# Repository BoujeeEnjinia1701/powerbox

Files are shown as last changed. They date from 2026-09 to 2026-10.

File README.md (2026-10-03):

# PowerBox

     

**Area:** CleanTech · **TRL:** 3 of 9 (proof of concept on paper) · **Value-engineering target:** USD 450, excluding the shared SwapCell pack (estimated cost USD 483) · **Difficulty:** 3 of 5

Standalone multi-input power station built around a SwapCell battery pack. It charges from a solar panel, the grid or a SunSpoke bike, and powers devices through USB, 12 V DC and a small AC outlet. It never connects to household wiring.

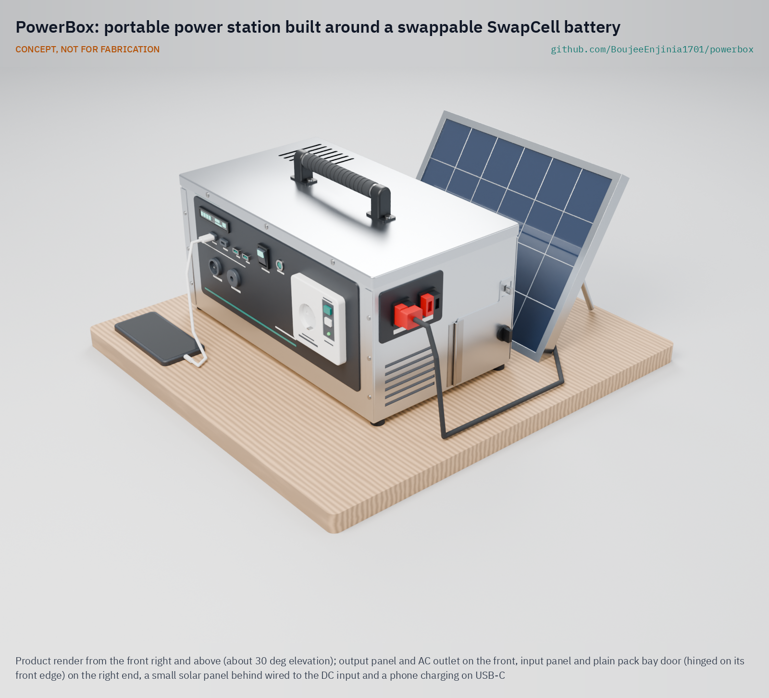
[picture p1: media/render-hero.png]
PowerBox: portable power station built around a swappable SwapCell battery, product render


[Exploded render](media/render-exploded.png) · [Detail render](media/render-detail.png) · [Interactive 3D model](media/viewer.html) · [Concept blueprint (PDF)](media/concept-blueprint.pdf) · [General arrangement (PDF)](cad/drawings/PBX-DWG-001.pdf) · [Prototype build plan](docs/05-build-plan.md) · [Design decisions](docs/06-design-decisions.md) · [Review note](docs/REVIEW.md)

## Concept rationale

A power station is only as useful as its battery, and in most commercial units the battery is sealed in. PowerBox is built around the portfolio's shared SwapCell pack instead, so the same battery can charge on a SunSpoke e-bike, a SwapCell dock or a solar panel and then run lights, phones, a radio and a router at home. A worn pack is replaced rather than the whole box. The box has no AC inlet and grid charging goes through a certified external charger, so it cannot back-feed household wiring through an ordinary plug.

The design is open and garage-buildable because the households that need it most are often the ones least served by sealed, imported products. A folded aluminium case, off-the-shelf certified modules for everything at mains voltage and a documented BOM mean a local technician can build, diagnose and repair it, and a community charging point can swap packs between boxes.

## Burning platform

In 2023 more than 666 million people still had no access to electricity, 85 % of them in sub-Saharan Africa ([WHO, IEA, IRENA, UNSD, World Bank, *Tracking SDG 7*, 2025](https://www.who.int/news/item/25-06-2025-energy-access-has-improved--yet-international-financial-support-still-needed-to-boost-progress-and-address-disparities)). Many more are connected but cannot rely on the grid: South Africa had load shedding on 290 days and for 6,948 hours in 2023, its worst year on record ([CSIR, 2025](https://www.csir.co.za/sites/default/files/2025-09/Utility%20Statistics%20Report_Jan%202025_Final.pdf)).

Rich grids fail too, and long outages fall hardest on poorer households. After Hurricane Maria in 2017, Puerto Rico lost an estimated 3.9 billion customer hours of electricity, the longest blackout in US history, and low-income residents waited longest for power to return ([Román et al., *PLOS ONE*, 2019](https://journals.plos.org/plosone/article?id=10.1371%2Fjournal.pone.0218883)).

## Where it could be used

### By industry

| Industry | Use |
| --- | --- |
| Households | Evening light, phone charging, radio and home internet through outages, recharged from solar or the grid |
| Community charging and small retail | Phone and lamp charging for a fee at market stalls and kiosks, with packs swapped between boxes and a dock |
| Humanitarian and disaster response | Quiet, fume-free power in shelters and homes after storms, earthquakes and grid attacks |
| Last-mile e-mobility | A home end for SunSpoke and other SwapCell vehicles, so a ridden pack powers the house at night |
| Education and training | A teaching platform for batteries, MPPT, inverters and electrical safety in schools and makerspaces |
| Electronics repair trade | An open, standard-parts design that local technicians can build, service and adapt |

### By country or region

| Country or region | Why it matters there |
| --- | --- |
| Nigeria | About 40 % of people lacked electricity access in 2023, and connected households saw about seven outages a week ([World Bank, *Atlas of Global Development*](https://data360.worldbank.org/en/atlas/electricity-access/)) |
| Democratic Republic of the Congo | About 80 % of the population lacked electricity access in 2023 ([World Bank, *Atlas of Global Development*](https://data360.worldbank.org/en/atlas/electricity-access/)) |
| South Africa | Load shedding on 290 days in 2023 ([CSIR, 2025](https://www.csir.co.za/sites/default/files/2025-09/Utility%20Statistics%20Report_Jan%202025_Final.pdf)) |
| Ukraine | Attacks destroyed about 9 GW of generating capacity by 2024, and some cities had blackouts of 12 h or more a day that summer ([UN Human Rights Monitoring Mission in Ukraine, 2024](https://ukraine.ohchr.org/en/Attacks-On-Ukraines-Electricity-Infrastructure)) |
| Puerto Rico (United States) | Hurricane Maria caused the longest blackout in US history, with rural municipalities averaging 131 days without power ([Román et al., 2019](https://journals.plos.org/plosone/article?id=10.1371%2Fjournal.pone.0218883)) |
| Japan | The 2018 Hokkaido Eastern Iburi earthquake cut power to about 2,950,000 homes across almost all of Hokkaido ([Japanese Red Cross Society](https://www.jrc.or.jp/english/relief/2020/0804_009751.html)) |

## What sparked the idea

The starting point was Winter Storm Uri in February 2021, when much of Texas lost power for days in freezing weather. The Texas Department of State Health Services counted 246 storm-related deaths, including 19 fatal carbon monoxide poisonings from improper use of generators, grills and heating equipment ([Texas DSHS, 2021](https://www.dshs.texas.gov/sites/default/files/news/updates/SMOC_FebWinterStorm_MortalitySurvReport_12-30-21.pdf)). The fuel-burning fallbacks that households reach for in an outage can be deadly indoors. That points at a silent battery box with no combustion and no way to back-feed the house, sized realistically for lights, phones, radio and internet, and charged from whatever is at hand.

## Problem

When the power goes out, households need a small, safe store of electricity for lights, phones, radio and internet, charged from whatever source is available: a solar panel, the grid when it is up or a charged pack brought home from an e-bike. Design with, not for: requirements must come from co-design sessions and field trials with the intended users through a local partner.

## Concept

Standalone multi-input power station built around a SwapCell battery pack. It charges from a solar panel, the grid or a SunSpoke bike, and powers devices through USB, 12 V DC and a small AC outlet. It never connects to household wiring.

It builds to SwapCell interface v0.3 as a station host: it wakes the pack through a coded INTERLOCK loop and can run loads while charging from solar. The sizing note shows 419 Wh usable per pack, 1.87 evenings of the reference load (1.81 with minimum-capacity cells, against a 1.8-evening target), a 2.1 h grid charge, 9.4 kg with the pack for the constructable design, and USD 482 of PowerBox parts against a USD 450 value-engineering target.

Full design precis: [docs/02-concept.md](docs/02-concept.md) · Sizing: [docs/04-calcs/01-sizing.md](docs/04-calcs/01-sizing.md) · General arrangement: [cad/drawings/PBX-DWG-001.pdf](cad/drawings/PBX-DWG-001.pdf)

## Key components

- Removable SwapCell 48 V pack (interface v0.3), with a fixed 12.8 V LiFePO4 pack as a documented fallback
- Multi-input charge controller (12 to 60 V DC and solar input with MPPT, external certified charger)
- USB-A and USB-C PD outlets
- 12 V DC outlets from a 30 A buck converter
- 300 W, 230 V pure sine inverter with its own AC outlet behind a 30 mA RCD
- State-of-charge display
- Enclosure with ventilation and handles

The working bill of materials is in [bom/bom.csv](bom/bom.csv).

## Building the prototype

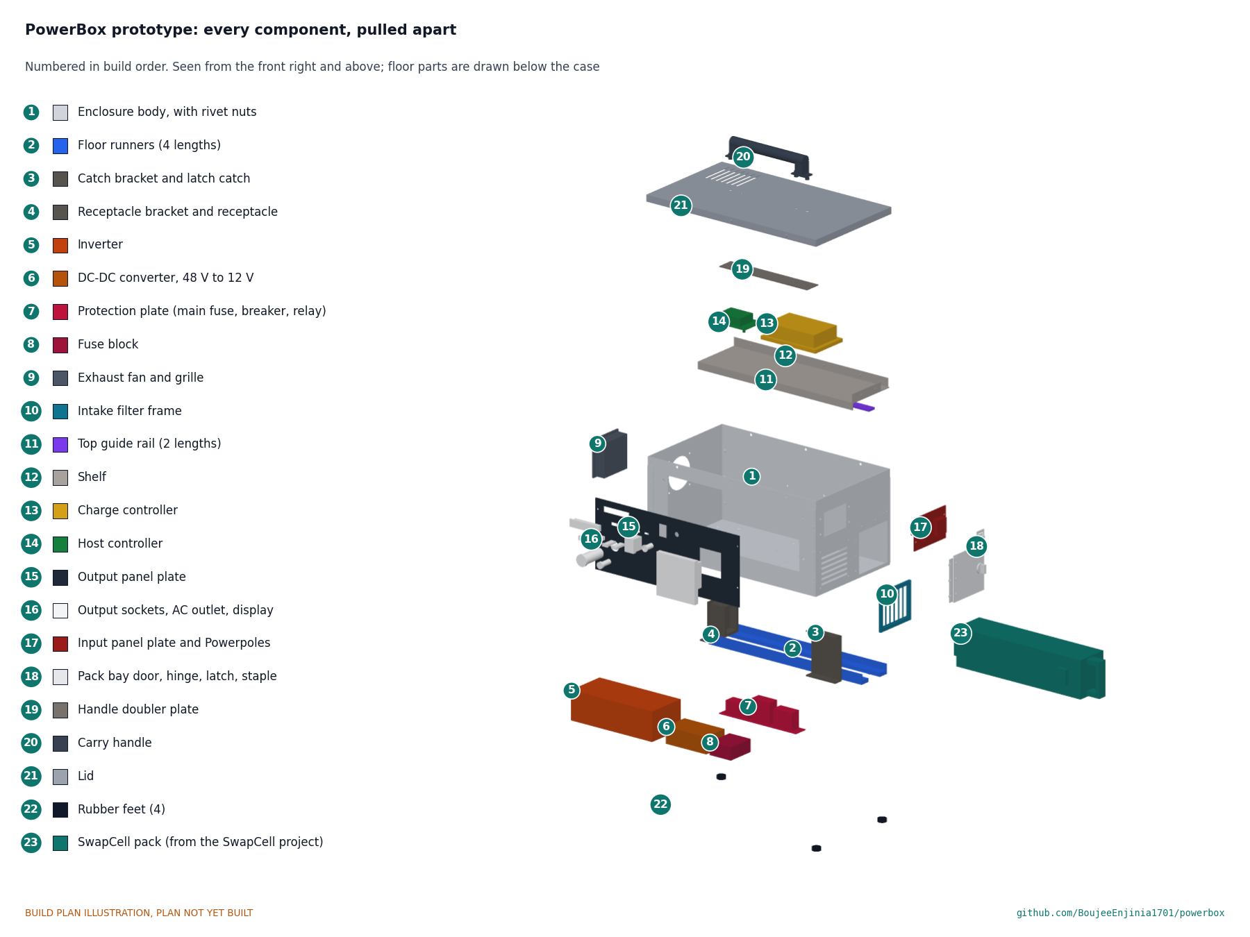
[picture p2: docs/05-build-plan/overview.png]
PowerBox prototype: every component pulled apart and numbered in build order


The [prototype build plan](docs/05-build-plan.md) (PBX-BLD-001) shows, in pictures, how to make each of PowerBox's 23 components and put them together in sixteen steps; nothing has been built yet. The made parts are a folded aluminium case, lid and shelf, two folded brackets, a door and two panel plates cut from sheet, and printed runners, a guide rail and a filter frame; the power modules are bought and wired at block level. Writing the plan made the design buildable: the lid now fits over the walls, the pack rests on guided runners, the shelf, brackets and receptacle are fixed, the door has a hinge, cam latch and padlock hasp, and the sockets sit in panel plates over windows in the walls (PBX-DDR-003, accepted by Amish on 2026-10-02). Every picture is drawn from the model, which checks that each part touches what it should and clears what it should not.

## Safety

> Standalone use only: never connect the AC output to a wall outlet or household wiring, because back-feeding endangers utility workers and is illegal. Contains a lithium battery pack. Use a BMS with cell-level protection, fuse the pack, and charge on a non-combustible surface.

## Repository layout

| Folder | Contents |
| --- | --- |
| `docs/` | Problem, concept, requirements, calculations and design decisions |
| `cad/src/` | build123d Python source, the source of truth for all geometry |
| `cad/step/`, `cad/stl/` | Exported models for FreeCAD, other CAD tools and printing |
| `cad/drawings/` | 2D sketches and dimensioned drawings |
| `bom/` | Bill of materials |
| `electronics/` | KiCad schematics and PCB layouts |
| `firmware/` | Microcontroller code |
| `media/` | Renders, perspectives and photos |
| `build-log/` | Dated prototyping notes |

## Documentation

Controlled documents follow the portfolio [documentation standard](.kit/STANDARDS.md). Each carries a document ID (PBX-PRC-001 for the precis), a version and a revision history. Branded PDFs are built with `python .kit/render.py` and attached to GitHub Releases when a document is tagged, for example `PBX-PRC-001/v1.0`.

## Credits

Designed by Amish Chadha. See [CONTRIBUTORS.md](CONTRIBUTORS.md) for roles. To cite this design, use [CITATION.cff](CITATION.cff) (GitHub shows it as "Cite this repository").

AI assistance (Claude) was used to accelerate concept renders, prototype documentation and first-pass sizing calculations. Design direction and all decisions are Amish Chadha's, recorded in this repository's decision records (`docs/decisions/`).

## Licenses

- **Hardware** (CAD, drawings, BOM, electronics): [CERN-OHL-S v2](LICENSE)
- **Software** (firmware, scripts, notebooks): [MIT](LICENSE-SOFTWARE)

A project of the [Design Molecule](https://designmolecule.com) lab.

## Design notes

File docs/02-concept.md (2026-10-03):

---
doc_id: PBX-PRC-001
title: PowerBox design precis
project: PowerBox
doc_type: Design precis
version: "0.8"
status: Draft
date: '2026-10-02'
author: Amish Chadha
license: CERN-OHL-S-2.0
revisions:
- version: "0.1"
  date: '2026-09-24'
  author: Amish Chadha
  change: Initial scaffold
- version: "0.2"
  date: '2026-09-24'
  author: Amish Chadha
  change: Populate to TRL 2 (architecture, first-order numbers, input and output specification, safety, media)
- version: "0.3"
  date: '2026-09-24'
  author: Amish Chadha
  change: Removed StepGen as a charging source after StepGen became a walking vehicle (Amish, 2026-09-24)
- version: "0.4"
  date: '2026-09-25'
  author: Amish Chadha
  change: TRL 3. SwapCell interface v0.3 (wake, station mode, latch class); Amish's decisions recorded (PBX-DDR-001); numbers checked against PBX-CAL-001; 30 A buck; general arrangement PBX-DWG-001
- version: "0.5"
  date: '2026-09-25'
  author: Amish Chadha
  change: Recommendations accepted by Amish (DDR-002)
- version: "0.6"
  date: '2026-10-01'
  author: Amish Chadha
  change: Constructable design (PBX-DDR-003), with lid, bay, door and panel details, mass, size and cost; budget treated as a value-engineering target
- version: "0.7"
  date: '2026-10-02'
  author: Amish Chadha
  change: "Decisions of 2026-10-02: R2 restated (met on paper), national AC socket with bonded earth, bare aluminium case, lit rocker switch, per-port metering, theft resistance, first candidate partner type, SwapCell transition action"
- version: "0.8"
  date: '2026-10-02'
  author: Amish Chadha
  change: "Cost USD 483 (USD 33 over the target) with the lit rocker main switch (PBX-CAL-001 v0.4); figures and pictures regenerated"
---

# PowerBox design precis

PowerBox is an aluminium carry case about the size of a small toolbox (460 x 260 x 220 mm body, 480 x 279 x 275 mm overall) with a SwapCell pack sliding into a bay through an end door. A charge controller takes DC from a solar panel, a certified external charger takes grid power, and a charged pack from a SunSpoke bike can simply be swapped in. Power leaves through USB-C PD, USB-A, 12 V sockets and one 300 W, 230 V pure sine AC outlet behind a 30 mA RCD. It never connects to household wiring. The sizing note PBX-CAL-001 shows one pack gives 419 Wh usable, which runs the reference evening of lights, phones, radio and a router **1.87 times (1.81 with minimum-capacity cells), above the 1.8 evenings of R2** as Amish restated it on 2026-10-02. The constructable design (PBX-DDR-003) weighs about 9.4 kg with the pack. Value-engineering target: USD 450. Estimated cost of the constructable design: USD 483 without the pack (USD 33 over the target). How to build the prototype is in the build plan PBX-BLD-001.

PowerBox builds to **SwapCell interface v0.3**. It is a station host (item C), so it can run loads while charging from solar; its receptacle carries the 10 kΩ INTERLOCK coding resistor that wakes a sleeping pack (item W); and its bay uses a class D latch catch (item V).

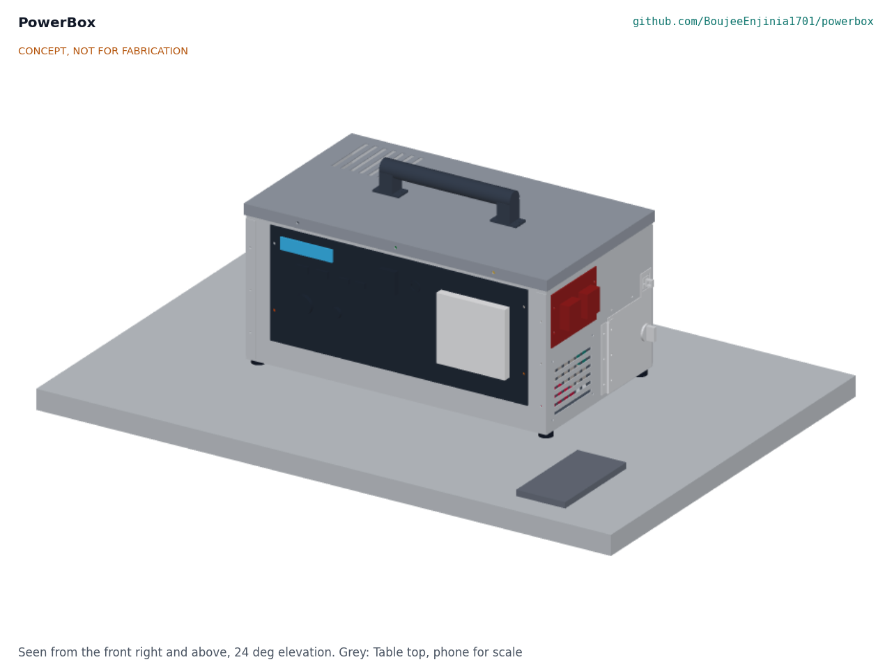
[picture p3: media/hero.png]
Hero render


*Figure 1. PowerBox on a table, with a phone for scale. Output panel on the front, input panel and pack bay door on the right end. Rendered from the parametric model `cad/src/model.py`.*

## How it works

1. **Charge.** Energy comes in through one of three paths, all controlled by the host controller:
   - **DC input** (a solar panel or another 12 to 60 V DC source, up to 200 W) goes through a buck-boost charge controller that tracks the source's maximum power point and charges the pack at up to 54.6 V.
   - **Grid** goes through a certified external 54.6 V, 5 A charger brick with a DC plug. PowerBox itself has no AC inlet, so it cannot be plugged into anything that would back-feed.
   - **SunSpoke** charges the pack while riding or at its own 100 W panel. The rider brings the charged SwapCell pack home and swaps it in. SunSpoke's panel can also plug into the DC input directly. StepGen, a walking vehicle, runs on the same SwapCell pack, so a pack can move between PowerBox and StepGen in the same way.
2. **Store.** The SwapCell pack (13S2P lithium-ion, 46.8 V nominal, 468 Wh nameplate) lies on one of its guide faces on floor runners, with its latch face toward the front of the case, and mates through the SwapCell blind-mate connector at the far end of the bay. A class D catch on a bracket at the front of the bay takes the pack's latch pawl, and the closed door stops the handle.
3. **Wake and handshake.** Seating the pack closes the INTERLOCK loop through the receptacle's 10 kΩ coding resistor, which wakes the pack. With no heartbeat after 2 s the pack enters legacy discharge (15 A limit), which powers the host; the host then sends a station heartbeat (host type 3) requesting mode 2 (discharge) or mode 4 (charge-discharge). A pack that fell asleep in the bay is woken with a recessed wake button on the front panel, which briefly opens the INTERLOCK loop.
4. **Convert and deliver.** The 39 to 54.6 V bus feeds a 48 V to 12 V, 30 A buck converter for the 12 V sockets and the USB-C PD and USB-A modules, and a 48 V input, 300 W pure sine inverter for the AC outlet. The inverter is switched in through its own relay and pre-charge resistor.
5. **Charge while in use.** When a source and a load are both present the host requests mode 4 and keeps net charge current at or below 5.0 A. With the grid charger connected (a fixed 5 A), the host limits the solar controller to the present load current.
6. **Inform.** A small display shows state of charge, input and output power and estimated time remaining, read from the pack's CAN messages, and the energy and charge sessions counted per port, labelled as approximate and not for billing. The host switches the inverter off after 10 min below 5 W and returns to off after 30 min idle.
7. **Protect.** A 30 A main fuse, a 20 A breaker on the inverter feed, per-output fuses, thermostatic fan control and the pack's own BMS limits guard against faults.

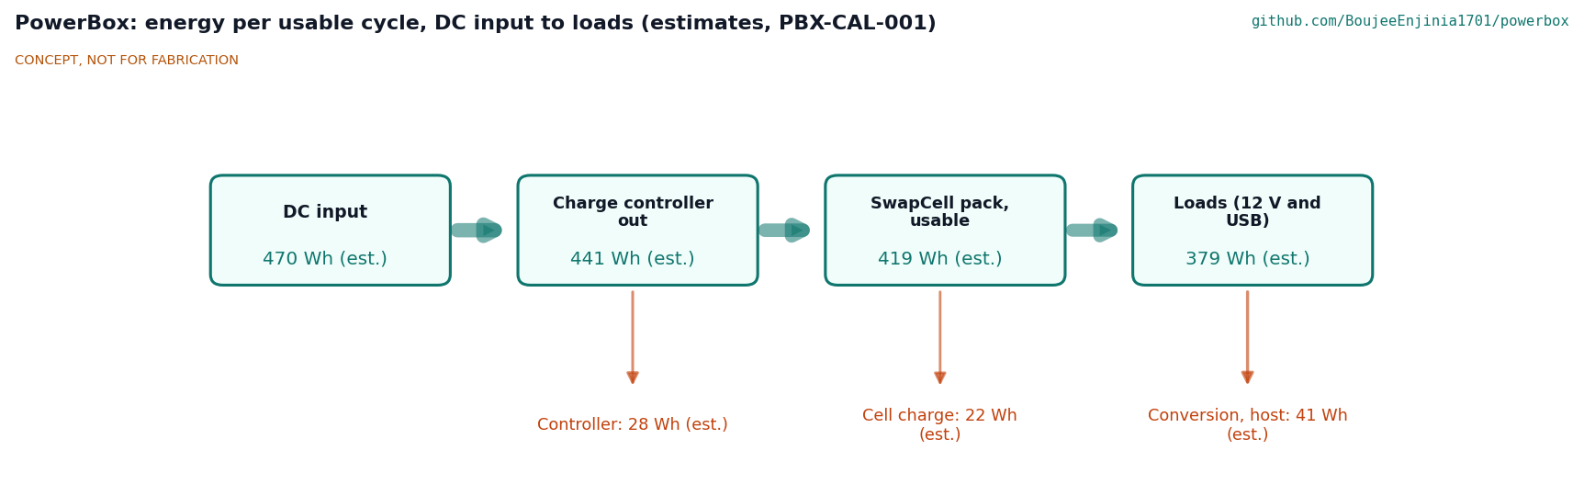
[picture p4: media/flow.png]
Energy flow


*Figure 2. Energy per usable cycle, DC input to loads, from PBX-CAL-001. All values are estimates: controller 94 %, cell charge 95 %, output conversion for the reference evening mix of 12 V and USB loads.*

## Main components

*Table 1. Main components. Numbers match `bom/bom.csv` and Figure 4.*

| # | Component | Choice | Notes |
| --- | --- | --- | --- |
| 1 | Enclosure body | Folded 1.2 mm aluminium tub, 460 x 260 x 220 mm | Spreads heat and resists fire better than plastic. Decided by Amish, 2026-09-25 |
| 2 | Lid | 1.2 mm aluminium with a 12 mm skirt and exhaust slots at the back | Removable for service |
| 3 | Carry handle | Folding bar handle on the lid, 200 mm span | Rated 15 kg or more |
| 4 | SwapCell pack | SwapCell interface v0.3 reference pack, 468 Wh, 2.85 kg | Priced once in the SwapCell BOM, not here. Removable pack decided by Amish, 2026-09-25 |
| 5 | Pack bay | Printed floor runners with guide lips and a top guide rail (1 mm clearance per side), folded catch bracket with the class D catch, folded 2 mm shelf above, SwapCell receptacle on a floating mount with a 10 kΩ INTERLOCK coding resistor | Horizontal side-loading bay decided by Amish, 2026-09-25 |
| 6 | Pack bay door | Door on the right end, hinged on its front edge, thumb-turn cam latch, padlock hasp and staple (PBX-DDR-003) | Second stop behind the pack handle |
| 7 | Multi-input charge controller | Buck-boost DC-DC, 12 to 60 V in, 200 W, CC-CV output set by the host | One DC input decided by Amish, 2026-09-25; MPPT in host firmware |
| 8 | Host controller | ESP32 with CAN transceiver, relays and current sensors | SwapCell station host; charge control, auto-off, display |
| 9 | Inverter | 300 W pure sine, 48 V input, 600 W for 1 s, 230 V 50 Hz, output isolated so the neutral can be bonded | AC region decided by Amish, 2026-09-25 |
| 10 | DC-DC converter | 48 V to 12 V, 30 A buck | Resized from 20 A by PBX-CAL-001 |
| 11 | Output panel | USB-C PD 100 W and 60 W, 2 x USB-A, 2 x 12 V sockets, lit rocker main switch, recessed wake button | Front face |
| 12 | AC outlet | Single 230 V outlet behind a 30 mA RCD | Only mains-voltage point on the box |
| 13 | Display | 2.4 in TFT or e-paper | State of charge, power in and out, time left |
| 14 | Input panel | 2 x Anderson Powerpole PP45: DC in, charger in | Right end, above the bay door |
| 15 | Exhaust fan | 80 mm 12 V fan, thermostatic; filtered intake slots on the right end | Pulls air across the case and out of the left end and lid |

Items 16 (protection and wiring), 17 (grid charger brick) and 18 (hardware) are in the BOM but not modelled. The general arrangement is drawing PBX-DWG-001 (`cad/drawings/PBX-DWG-001.pdf`), generated from `cad/src/model.py`.

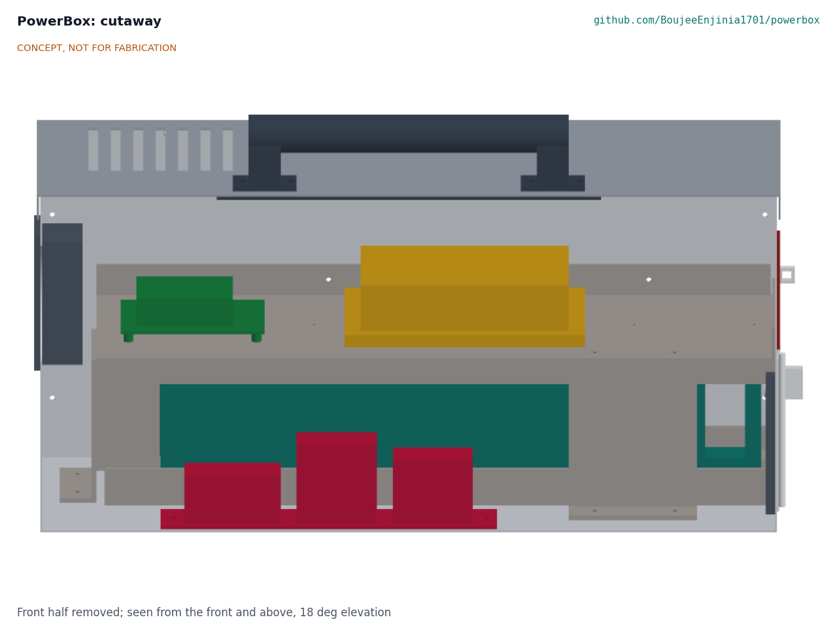
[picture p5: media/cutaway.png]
Cutaway


*Figure 3. Section looking from the front: inverter (9) on the floor at the front, SwapCell pack (4) in its bay at the back, charge controller (7) and host (8) on the shelf above, fan (15) on the left end, input panel (14) and bay door (6) on the right end.*

## Key numbers

All values come from PBX-CAL-001 (`docs/04-calcs/sizing.py`) and are paper estimates. Assumptions: the SwapCell v0.3 reference pack (466 Wh at 0.2C, 39.0 to 54.6 V); 10 to 100 % state of charge; 12 V buck 94 %, USB modules 93 % from 12 V, charge controller 94 % nominal, cell charge 95 %, grid charger 90 %; inverter efficiency and idle draw typical of 48 V, 300 W pure sine units (no datasheet yet).

*Table 2. Energy, charge times, size and cost.*

| Quantity | Value | Basis | Requirement |
| --- | --- | --- | --- |
| Usable energy | 419 Wh (407 Wh with minimum cells) | 90 % of 466 Wh | R1 met (400 Wh) |
| Reference evening (Table 1 of PBX-REQ-001) | 225 Wh from the pack | 165 Wh for 12 V loads at 94 %, 55 Wh for USB at 87 %, 5 Wh host and idle converters over 5 h | |
| Evenings per pack | 1.87 | 419 / 225 | R2 met on paper (target 1.8, restated 2026-10-02) |
| Grid charge, 10 to 100 % | 2.1 h; 492 Wh from the wall | 1.5 h CC at 5 A, then 0.6 h CV; charger 90 % | R4 met (3 h) |
| Solar, 200 W panel | 634 Wh per clear day at the pack; full in 0.70 day | 4.5 peak sun hours, 0.75 derating, 94 % controller | R5 met |
| Solar, SunSpoke 100 W panel | 317 Wh per clear day; one evening in 0.75 day | Same basis | |
| Charge controller efficiency | 90.5 % at 12 V and 200 W; 93 % or more elsewhere from 40 to 200 W | Loss model, no datasheet | R6 at risk |
| Station mode, net charge | 4.48 A worst case; 2.74 A typical with the router | 200 W at 94 % into 42 V; limit 5.0 A | Within the SwapCell limit |
| 12 V bus demand, all DC outputs | 318 W, 26.5 A | 120 W sockets plus 184 W USB at 93 % | 30 A buck (was 20 A) |
| Peak pack current | 11.5 A at 400 W output; 20.9 A during a 1 s inverter surge | At 39.0 V | Within 20 A continuous and 35 A peak |
| Inverter idle, if left on | 192 Wh per day, 46 % of usable | 8 W for 24 h | Auto-off after 10 min (R8) |
| Standby, off | 3.2 % per month | 2.5 % self-discharge plus 100 µA BMS sleep | R8 met (5 %) |
| Standby, ready | 0.6 W, 14.4 Wh per day | ESP32 0.2 W, CAN and BMS 0.2 W, display 0.2 W | R8 met (1.0 W); host returns to off after 30 min idle |
| Heat at full load while charging | 60 W; air rise about 6 K with the fan | Inverter 41 W, buck 6.4 W, controller 12 W, host 1 W | Fan needed |
| Mass | 9.4 kg (20.8 lb) with pack | Pack 2.85, body 1.22, lid 0.47, inverter 1.20, other parts 3.68 kg (constructable design) | R10 met (10 kg); charger brick about 0.8 kg extra |
| Size | 480 x 279 x 275 mm overall | Parametric model | R10 met, 5 mm spare in height |
| PowerBox parts cost | USD 483 | `bom/bom.csv`, indicative prices | Value-engineering target USD 450: USD 33 over |
| Cost with one SwapCell pack | USD 897, for reference | USD 483 plus USD 414 from the SwapCell BOM | Pack excluded from this budget (decided) |

*Table 3. Runtime on one full pack (419 Wh usable) for single loads.*

| Load | Output | Power at the load | Drawn from the pack | Runtime |
| --- | --- | --- | --- | --- |
| Wi-Fi router and fibre terminal | 12 V DC | 12 W | 12.8 W | about 33 h |
| Three 5 W LED bulbs | 12 V DC | 15 W | 16.0 W | about 26 h |
| Radio | 12 V DC | 5 W | 5.3 W | about 79 h |
| Phone charges | USB | 12 Wh each | 13.7 Wh each | about 31 charges |
| Laptop | USB-C PD | 45 W | 51.5 W | about 8 h |
| Small LED TV | AC | 60 W | 70.6 W | about 6 h |
| Desk fan | AC | 25 W | 32.1 W | about 13 h |
| Maximum AC load | AC | 300 W | 340.9 W | about 1.2 h |
| Refrigerator or kettle | AC | Out of scope: starting surge or power beyond the 300 W inverter | | |

*Table 4. Input and output specification.*

| Port | Type and connector | Voltage | Power or current | Notes |
| --- | --- | --- | --- | --- |
| DC in | Anderson PP45, red and black | 12 to 60 V DC | 200 W maximum, 16.7 A at 12 V | Solar panel or SunSpoke panel; MPPT; TVS and reverse-polarity protection; 20 A fuse |
| Charger in | Anderson PP45, keyed differently from DC in | 54.6 V DC from the certified brick | 5 A | Grid charging only through the external charger |
| Pack | SwapCell blind-mate connector, interface v0.3 | 39.0 to 54.6 V | 20 A continuous available; PowerBox uses 11.5 A or less | CAN 2.0B at 250 kbit/s; 120 Ω termination in PowerBox; 10 kΩ INTERLOCK coding resistor; station host type 3 |
| USB-C PD 1 | USB-C | 5 to 20 V | 100 W | Laptops |
| USB-C PD 2 | USB-C | 5 to 20 V | 60 W | Phones, tablets |
| USB-A 1, 2 | USB-A | 5 V | 12 W each | Phones, lamps, radios |
| 12 V DC 1 | Car socket | 12 V regulated | 10 A shared with 12 V DC 2 | Router, lights, radio |
| 12 V DC 2 | 5.5 x 2.1 mm barrel | 12 V regulated | As above | |
| AC out | One 230 V socket behind a 30 mA RCD: the national socket of the first partner's country with its earth pin bonded to the case, never a universal socket | 230 V 50 Hz, pure sine | 300 W continuous, 600 W for 1 s | Auto-off; never to be connected to household wiring |
| Total output | | | 400 W | Host limit to keep pack current and heat in range |

## Key design choices

All of these were decided by Amish on 2026-09-25 (go with recommendation), PBX-DDR-001, unless marked otherwise.

- **Removable SwapCell pack, with a fixed internal pack as fallback.** One battery moves between PowerBox, SunSpoke and the SwapCell dock, and a worn pack is replaced without discarding the box. The fixed 12.8 V LiFePO4 pack (about 30 Ah, 384 Wh, about $110) with a 12 V inverter and no CAN stays only as a documented fallback.
- **Side-loading horizontal bay.** Laying the pack along the case length with a door on the end keeps the case low and stable; a top-loading bay would make it about 450 mm tall.
- **One DC input with maximum power point tracking.** A second independent input (about $30 more) only if users need two panels at once.
- **Grid charging only through a certified external charger.** No mains-input electronics in the box and no AC inlet. The brick can be omitted where a SwapCell dock is on hand ($399 of parts).
- **A 300 W, 230 V AC outlet, with a DC-only variant.** The DC-only variant saves about $92 and removes all mains voltage from the box. 120 V 60 Hz is a later variant.
- **Folded aluminium enclosure.**
- **No human-powered input now.** A pedal generator could later be a separate repo that plugs into the DC input.
- **Station host on SwapCell interface v0.3.** Wake through the coded INTERLOCK loop (item W), charge-discharge mode 4 as a station host (item C) and a class D latch catch with the door as a second stop (item V). These replace the keep-alive cell and local pass-through workarounds considered at TRL 2.
- **Budget.** `budget_usd` stays at USD 450, a value-engineering target rather than a limit (Amish, 2026-10-01), and covers the PowerBox parts, including the grid charger; the SwapCell pack is priced once in the SwapCell BOM.
- **Wake button, 30 A buck and fuse ratings.** Proposed in PBX-CAL-001 and decided by Amish, 2026-09-25: go with recommendation (PBX-DDR-002). A recessed, normally closed wake button in series with the 10 kΩ coding resistor; a 30 A (360 W) 48 V to 12 V buck; every 48 V fuse rated 60 V DC or more with at least 1 kA breaking capacity, as in PBX-CAL-001 Table 3.

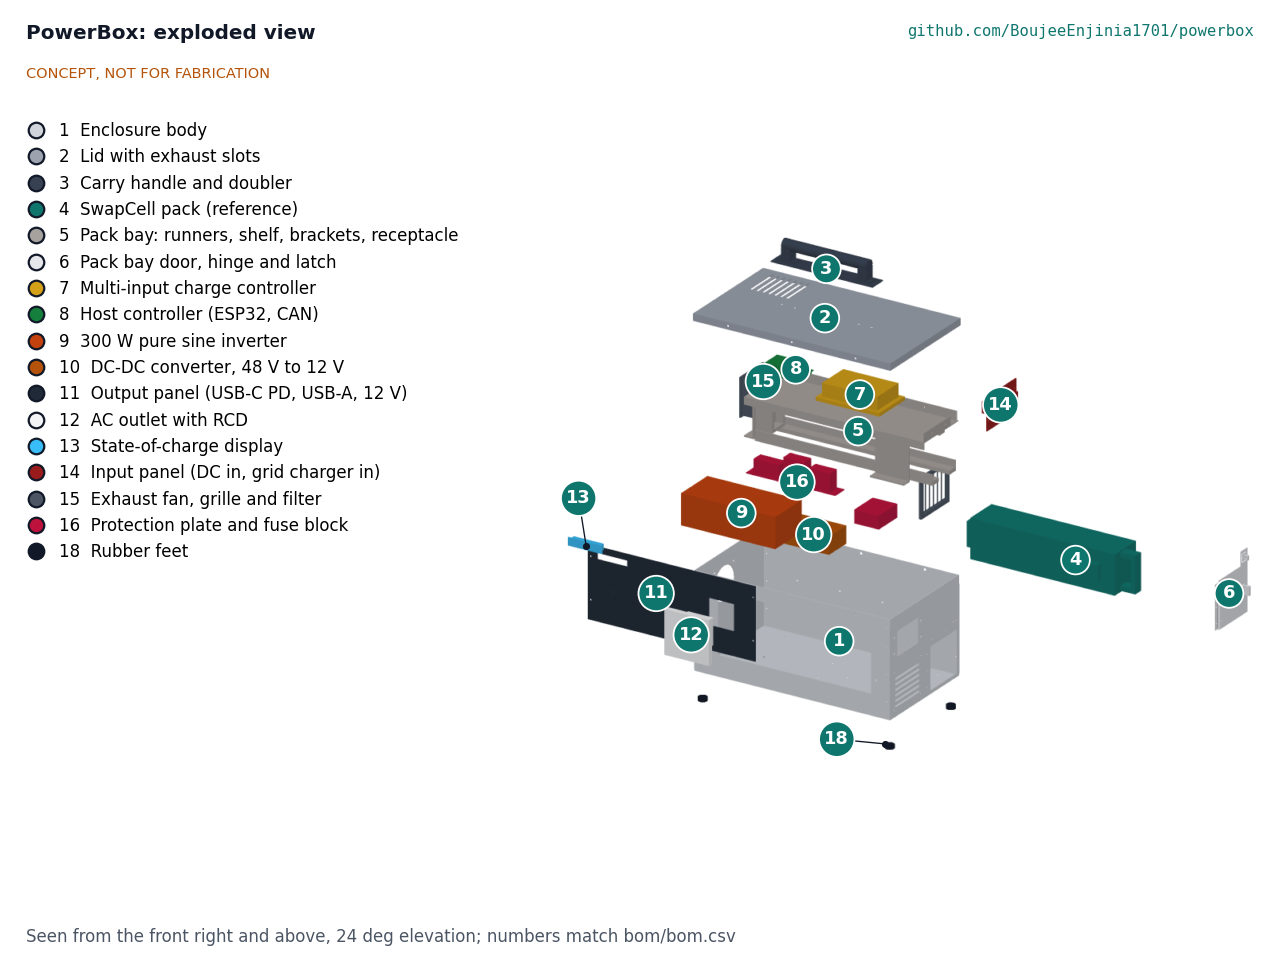
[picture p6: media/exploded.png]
Exploded view


*Figure 4. Exploded view with BOM numbers.*

## Safety

> **Safety:** PowerBox is standalone only. Never connect the AC outlet to a wall outlet, household wiring, a distribution board or a transfer switch. Back-feeding can kill utility workers repairing lines during an outage, can damage the box and the home's wiring, and is illegal.

> **Safety:** The SwapCell pack is a 468 Wh lithium-ion battery that can deliver about 500 A into a short. Use it only with the SwapCell BMS, keep the pack's fuse and PowerBox's 30 A main fuse in place, and never charge a damaged, swollen or wet pack. Charge on a non-combustible surface, away from exits, beds and children, and do not cover the box while charging. Keep a smoke alarm in the room.

> **Safety:** The AC outlet carries 230 V. It is behind a 30 mA RCD, and for the RCD to work the inverter's output neutral must be bonded to the case and the protective earth pin, as in a vehicle or boat installation. This needs an inverter whose output is isolated from its DC input; many small inverters float or are not isolated. This must be confirmed from the chosen inverter's datasheet before any build.

- **AC socket and case finish.** The AC outlet is the national socket of the first partner's country, with its earth pin bonded to the case; never a multi-standard universal socket, which can accept a plug without a reliable earth contact and defeat the RCD arrangement. The case is the earth bond for the RCD: it stays bare 5052 aluminium for the prototype, and any later powder coat must leave the bond points bare (decided by Amish, 2026-10-02).
- **No back-feed by design.** There is no AC inlet on the box, and grid charging uses a certified external charger with a DC plug, so no cable can join PowerBox's AC output to a live circuit through an ordinary plug. The user guide and labels must still warn against double-male cords and improvised connections.
- **Extra-low-voltage bus.** The battery side stays at 54.6 V or less, below the 60 V DC limit for extra-low voltage, so only the inverter output and the charger brick input are at mains voltage.
- **Fuse ratings.** Every fuse on the 48 V side must be rated for 60 V DC or more and at least 1 kA breaking capacity, because a short at the pack could draw about 496 A (PBX-CAL-001 section 6).
- **Coded interlock.** The receptacle must carry the 10 kΩ coding resistor. A direct link from INTERLOCK to SGND reads as a fault and the pack stays dead, which fails safe. The wake button opens the loop, so pressing it while the box is running cuts the output briefly; it is recessed to prevent accidental presses.
- **Charging while in use.** In mode 4 PowerBox acts as a charger. The host keeps net charge at or below 5.0 A and the pack voltage at or below 54.6 V, and limits the solar controller whenever the fixed 5 A grid charger is connected. The pack refuses charge below 0 °C and above 45 °C cell temperature.
- **Ventilation.** At full load while charging the case holds about 60 W of heat. A thermostatic fan pulls air through filtered intake slots on the right end and out through the left end and lid. The host derates or shuts outputs down above an internal temperature limit, and the pack enforces its own limits. The case must not be used in a closed cupboard or bag.
- **Cords and connectors.** Keyed Powerpole connectors prevent the charger and DC inputs from being swapped. Input and output cords must be rated for their current, kept out of walkways and never run under rugs. The 12 V sockets are fused at 10 A.
- **Pack handling.** The bay door keeps fingers away from the connector, and the SwapCell interlock keeps the pack output dead until it is fully seated.
- **Not a medical or life-safety supply.** PowerBox must not be relied on for oxygen concentrators or other life-support equipment.

## Open questions

Items that remain open after PBX-DDR-001 and PBX-DDR-002. None of them is TRL 4 work to be started now; TRL 4 is on hold by Amish's instruction.

- **R2 (decided 2026-10-02).** Restated as 1.8 evenings; the 10 % cut-off is kept and the reference evening is revisited with the first partner's users.
- **Legacy-to-station transition.** SwapCell interface v0.3 does not say whether a pack in legacy discharge accepts a station heartbeat and moves to mode 2 or 4 without opening its output. PowerBox's host is powered from the pack and depends on this. Kept with SwapCell as one cross-repo action shared with MotionCore, with an answer needed before PowerBox's interface is frozen; if the answer is no, a small hold-up capacitor for the host is planned across the mode change (decided by Amish, 2026-10-02).
- **Inverter selection.** Confirm idle draw, light-load efficiency and an isolated output whose neutral can be bonded for the RCD.
- **Charge controller selection (R6, at risk).** Confirm 90 % or more at 12 V and 200 W and at 40 W, and stable tracking.
- **Value engineering (R11).** The constructable design is USD 33 over the USD 450 value-engineering target on indicative prices; the savings worth trying are in the design decisions register (PBX-DEC-001).
- **Theft resistance and metering (decided 2026-10-02).** Thumb-turn cam latch and padlock hasp for the prototype, a keyed cam latch if the first partner runs an unattended or shared charging point; per-port energy and session counts on the display, not for billing.
- **First co-design partner (decided 2026-10-02).** A partner in a 230 V, 50 Hz region that runs or supplies community charging or solar home systems; the first candidate type to approach is a solar distribution charity such as SolarAid, which works in Zambia and Malawi. Nothing is agreed. The load profile, pack-swap routine and price must be validated with users.

Concept media: [blueprint sheet](../media/concept-blueprint.pdf), [interactive 3D model](../media/viewer.html).

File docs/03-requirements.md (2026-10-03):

---
doc_id: PBX-REQ-001
title: PowerBox requirements
project: PowerBox
doc_type: Requirements
version: "0.7"
status: Draft
date: '2026-10-02'
author: Amish Chadha
license: CERN-OHL-S-2.0
revisions:
- version: "0.1"
  date: '2026-09-24'
  author: Amish Chadha
  change: Initial scaffold
- version: "0.2"
  date: '2026-09-24'
  author: Amish Chadha
  change: First measurable requirements for TRL 2
- version: "0.3"
  date: '2026-09-24'
  author: Amish Chadha
  change: Removed StepGen as a charging source after StepGen became a walking vehicle (Amish, 2026-09-24)
- version: "0.4"
  date: '2026-09-25'
  author: Amish Chadha
  change: TRL 3. Record Amish's decisions (PBX-DDR-001), including the 230 V AC region and a budget that excludes the pack; SwapCell interface v0.3; status from PBX-CAL-001
- version: "0.5"
  date: '2026-10-01'
  author: Amish Chadha
  change: R10 and R11 status for the constructable design (PBX-DDR-003, PBX-CAL-001 v0.2); budget treated as a value-engineering target
- version: "0.6"
  date: '2026-10-02'
  author: Amish Chadha
  change: "R2 restated as 1.8 evenings (Amish, 2026-10-02, PBX-DEC-001 item 5); met on paper"
- version: "0.7"
  date: '2026-10-02'
  author: Amish Chadha
  change: "R11 cost restated to USD 483, USD 33 over the target, after the lit rocker main switch (PBX-CAL-001 v0.4)"
---

# PowerBox requirements

These requirements are checked by calculation in PBX-CAL-001 (TRL 3). They are still proposals, not user-validated needs, and will be revised after co-design sessions. On paper, nine are met, including R2 as restated by Amish on 2026-10-02 (1.87 evenings against 1.8); R6 is at risk, R11 is reported against its value-engineering target (USD 33 over), and R12 cannot be verified until users try a pack swap. The Status column gives the TRL 3 result.

| ID | Requirement | Target | Verification (TRL 3 or later) | Status (PBX-CAL-001) |
| --- | --- | --- | --- | --- |
| R1 | Store useful energy in one SwapCell pack | 400 Wh or more usable at the pack terminals, using 10 to 100 % state of charge | Calculation from SwapCell capacity and the host's discharge cut-off | Met, 419 Wh |
| R2 | Run a household through outage evenings | 1.8 evenings of the reference load profile (Table 1, 203 Wh at the loads) on one full pack, at the pack's 10 % cut-off (restated from 2 evenings by Amish on 2026-10-02, PBX-DEC-001 item 5) | Energy budget calculation including conversion losses and standby | Met on paper: 1.87 evenings (1.81 with minimum-capacity cells) |
| R3 | Accept four charging sources | (a) DC input 12 to 60 V, up to 200 W, with maximum power point tracking for a solar panel or another DC source; (b) grid through a certified external charger; (c) SunSpoke by swapping in a charged SwapCell pack; (d) SunSpoke's 100 W panel through the DC input | Design review against the input specification table | Met (design review) |
| R4 | Recharge quickly from the grid | 10 to 100 % in 3 h or less | Charger rating and SwapCell charge curve | Met, 2.1 h |
| R5 | Recharge from solar in a day | 10 to 100 % in one clear day (4.5 peak sun hours) with a 200 W panel | Solar yield calculation | Met, full in 0.70 day |
| R6 | Use DC and solar input efficiently at low power | DC input conversion efficiency 90 % or more from 40 to 200 W, and stable maximum power point tracking (no stall or hunting) as a panel's output changes with light and temperature | Converter efficiency data; later bench test with a solar panel or solar simulator | At risk, 90.5 % worst case in the loss model |
| R7 | Provide the outputs households use | 2 x USB-C PD (one 100 W, one 60 W), 2 x USB-A (12 W each), 2 x 12 V DC (10 A shared), 1 x AC outlet, 230 V 50 Hz, 300 W continuous pure sine (THD 3 % or less) behind a 30 mA RCD; total output limited to 400 W | Design review against the output specification table | Met (design review) |
| R8 | Waste little energy when idle | Off: 5 % or less of pack energy per month, including cell self-discharge. Ready (display on, outputs off): 1.0 W or less. Inverter switches itself off after 10 min below 5 W | Standby budget calculation; later measurement | Met, 3.2 % per month off, 0.6 W ready |
| R9 | Never back-feed household wiring | No AC input connector that can mate with an AC output; AC output only through a 30 mA RCD outlet with the inverter neutral bonded to the case; grid charging only through a certified external charger with a DC plug; DC bus 60 V or less | Design review and safety checklist | Met (design review) |
| R10 | Be carried by one adult | 10 kg (22 lb) or less with pack; 500 x 300 x 280 mm or smaller including handle; one top handle | Massing model, then weighing | Met, 9.4 kg, 480 x 279 x 275 mm (constructable design) |
| R11 | Keep to the value-engineering target | PowerBox parts against a value-engineering target of USD 450 (a hypothetical control target, not a limit; Amish, 2026-10-01), including the grid charger and excluding the SwapCell pack, which is priced once in the SwapCell BOM (decided by Amish, 2026-09-25) | Priced BOM | USD 483, USD 33 over the target |
| R12 | Swap packs and show status simply | Pack swapped by hand in 30 s or less without tools; display shows state of charge, input and output power and estimated time remaining, read from the SwapCell interface v0.3 CAN messages; a sleeping pack wakes through the INTERLOCK loop (v0.3 item W) | Design review; later timed trial with users | Not verifiable at TRL 3 |

## Assumptions

Table 1. Reference evening load profile (6 pm to 11 pm outage). Proposed for review; the real profile must come from co-design sessions.

| Load | Power | Hours | Energy at the load | Output used |
| --- | --- | --- | --- | --- |
| Three LED bulbs | 3 x 5 W | 5 | 75 Wh | 12 V DC |
| Wi-Fi router and fibre terminal | 12 W | 5 | 60 Wh | 12 V DC |
| Radio | 5 W | 4 | 20 Wh | 12 V DC |
| Four phone charges | about 12 Wh each | | 48 Wh | USB |
| **Total** | | | **203 Wh** | |

- The SwapCell pack is the reference 13S2P pack of SwapCell interface v0.3: 46.8 V nominal, 39.0 to 54.6 V, 468 Wh nameplate and 466 Wh at 0.2C (SWC-CAL-001). PowerBox is a station host (v0.3 item C) and its receptacle carries the 10 kΩ INTERLOCK coding resistor (item W).
- Solar input spends much of the day well below the panel rating (morning, evening and cloud), so the DC input often runs at 40 to 100 W.
- Refrigerators, kettles and other high-power or high-surge loads are out of scope (see PBX-PRB-001).
- Budget: the USD 450 value-engineering target in `project.yaml` covers the PowerBox itself (decided by Amish, 2026-09-25, PBX-DDR-001). A household that needs its own pack also buys a SwapCell pack, priced once in the SwapCell BOM at about $414 in prototype parts.
- R2: decided by Amish on 2026-10-02 (PBX-DEC-001, item 5): 1.8 evenings, which covers minimum-capacity cells (1.81); the 10 % cut-off is kept, since discharging to 3.5 % would shorten the shared SwapCell pack's life. The 203 Wh reference evening is not yet validated and is revisited with the first partner's users.

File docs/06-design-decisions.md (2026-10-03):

---
doc_id: PBX-DEC-001
title: PowerBox design decisions register
project: PowerBox
doc_type: Design decisions register
version: "0.3"
status: Draft
date: '2026-10-02'
author: Amish Chadha
license: CERN-OHL-S-2.0
revisions:
  - version: "0.1"
    date: '2026-10-01'
    author: Amish Chadha
    change: Register opened with the build plan; budget treated as a value-engineering target
  - version: "0.2"
    date: '2026-10-02'
    author: Amish Chadha
    change: "Amish approved the recommendations for all twelve open decisions on 2026-10-02 (PBX-DDR-003 accepted); moved to decisions made"
  - version: "0.3"
    date: '2026-10-02'
    author: Amish Chadha
    change: "Cost USD 483 (USD 33 over the target) with the lit rocker main switch; savings figure USD 433 without the grid charger"
---

# PowerBox design decisions register

Every design decision still to be made, and every decision made, in one place. Each decision is argued in full in its decision record under `docs/decisions/`; this register is the index Amish works from. The build plan (`docs/05-build-plan.md`) describes the design as it stands and does not list open decisions.

## Open decisions

None. All open decisions were decided on 2026-10-02.

## To confirm when parts are bought

| # | What to confirm | Why it matters | Source |
| --- | --- | --- | --- |
| 1 | The inverter's output is isolated from its DC input so its neutral can be bonded to the case and earth pin; its idle draw and light-load efficiency | The 30 mA RCD only works with a bonded neutral; idle draw sets the auto-off case | PBX-CAL-001 section 8; PBX-PRC-001 |
| 2 | The charge controller reaches 90 % or more at 12 V and 200 W and at 40 W, and tracks stably | R6 is at risk on the loss model | PBX-CAL-001 section 3 |
| 3 | The fuse block and its blade fuses are rated 58 V DC or more, and every 48 V fuse 60 V DC or more with at least 1 kA breaking capacity | A short at the pack could draw about 496 A | PBX-CAL-001 section 6; PBX-DDR-003 |
| 4 | The hole patterns of the class D catch, the receptacle's floating mount, and the inverter's and converter's feet | The catch bracket web, receptacle bracket web and floor holes are drilled to suit | PBX-DDR-003 |
| 5 | The cam latch grips a 1.2 mm door against a 1.2 mm wall, and its tongue reaches 15 mm | The tongue must turn behind the end wall | PBX-DDR-003, P7 |
| 6 | The cut-out sizes of every module in the output and input panel plates | The plate cut-outs are drawn from envelopes, not datasheets | PBX-DWG-110, PBX-DWG-111 |
| 7 | The rivet nut hole size (6.0 mm assumed for M4) and the heat-set insert hole sizes (5.6 mm for M4, 4.0 mm for M3) | Each maker gives its own | PBX-DDR-003 |
| 8 | The fan's flow through the filter, grille and 76 mm hole (half of 16 L/s free air assumed) | The 6 K air rise at full load depends on it | PBX-CAL-001 section 9 |

## Value engineering

Value-engineering target: USD 450 (a hypothetical control target, not a limit). Estimated cost of the constructable design: USD 483 for the PowerBox parts, excluding the shared SwapCell pack (USD 33 over the target). Main cost drivers and savings worth trying:

- The largest lines are the inverter (USD 70), the grid charger brick (USD 50), the output panel modules (USD 46), the protection parts and wiring (USD 38), the enclosure body (USD 38), the pack bay (USD 40), and the charge controller and buck converter (USD 30 each).
- Making the design constructable added USD 33 over the concept's USD 449: rivet nuts and windows in the body, the deeper lid skirt, the handle doubler, the shelf, brackets, runners and rail, the door hinge, cam latch and staple, the filter frame, the protection plate and the counted fixings.
- Savings worth trying: leave out the grid charger where a SwapCell dock is on hand (USD 50, bringing the parts to USD 433); the DC-only variant without the inverter and AC outlet (about USD 92, and no mains voltage in the box); quotes for the folded sheet parts as one batch from one shop; printing the brackets in place of folding them is not worth trying, since they carry the pack's latch load.

## Decisions made

| Date | Decision | Decided by | Record |
| --- | --- | --- | --- |
| 2026-09-24 | StepGen removed as a charging source; the DC input stays for solar and other DC sources | Amish, 2026-09-24 | PBX-PRC-001 v0.3 |
| 2026-09-25 | TRL 2 items 1 to 12: removable SwapCell pack, side-loading bay, one DC input with MPPT, grid charging through a certified brick only, 300 W AC outlet with a DC-only variant, folded aluminium case, 230 V 50 Hz with a 30 mA RCD, budget for the PowerBox parts only, no human-powered input, station mode, wake by coded INTERLOCK, class D catch | Amish: go with recommendation | PBX-DDR-001 |
| 2026-09-25 | Recessed normally closed wake button, 30 A buck converter, fuse ratings of PBX-CAL-001 | Amish: "i accept all your recommendations, go with them across all repos." | PBX-DDR-002 |
| 2026-09-30 | Fix the design assumptions so the design can be built, and record the changes | Amish: "If you are realising that the design cannot be built as per concept - fix the design assumptions to match and be physically feasible as you draw the illustrations." | PBX-DDR-003 (Draft; accepted on 2026-10-02, below) |
| 2026-10-01 | The budget is a value-engineering target, not a limit | Amish: "the budgets are a hypothethical control target to ensure we are thinking along a value engineering lens." | This register; PBX-CAL-001 v0.2 |
| 2026-10-02 | Design for construction accepted: the changes P1 to P12 of PBX-DDR-003 and their knock-on changes, as made | Amish: "i approve your recommendations for all 555 open decisions." | PBX-DDR-003, A4 |
| 2026-10-02 | Door hinged on its front edge, as modelled; the renders are updated to match | Amish: "i approve your recommendations for all 555 open decisions." | PBX-DDR-003, A1 |
| 2026-10-02 | Thumb-turn cam latch plus padlock hasp for the prototype; a keyed cam latch (about USD 3 more) if the first partner runs an unattended or shared charging point | Amish: "i approve your recommendations for all 555 open decisions." | PBX-DDR-001, item 15; PBX-DDR-003, A2 |
| 2026-10-02 | R10 mass margin of 0.58 kg accepted; the prototype is weighed at TRL 4 | Amish: "i approve your recommendations for all 555 open decisions." | PBX-DDR-003, A3 |
| 2026-10-02 | R2 restated as 1.8 evenings of the 203 Wh reference evening on one full pack (1.81 with minimum-capacity cells); the pack's 10 % cut-off is kept; the reference evening is revisited with the first partner's users | Amish: "i approve your recommendations for all 555 open decisions." | PBX-DDR-001, item 13 |
| 2026-10-02 | First partner: one in a 230 V, 50 Hz region that runs or supplies community charging or solar home systems where outages are routine. First candidate type to approach: a solar distribution charity such as SolarAid, which works in Zambia and Malawi | Amish: "i approve your recommendations for all 555 open decisions." | PBX-DDR-001, item 14 |
| 2026-10-02 | Energy and charge sessions counted per port in the host firmware and shown on the display, labelled as approximate and not for billing | Amish: "i approve your recommendations for all 555 open decisions." | PBX-DDR-001, item 16 |
| 2026-10-02 | The legacy-to-station question is kept with SwapCell as one cross-repo action shared with MotionCore, with an answer asked for before PowerBox's interface is frozen; if the answer is no, a small hold-up capacitor for the host is planned across the mode change | Amish: "i approve your recommendations for all 555 open decisions." | PBX-DDR-001, item 18 |
| 2026-10-02 | Bare 5052 aluminium case for the prototype; powder coat only for a product version, once priced, with the earth bond points masked | Amish: "i approve your recommendations for all 555 open decisions." | REVIEW 2026-09-26, item 4 |
| 2026-10-02 | AC socket: the national socket of the first partner's country, with its earth pin bonded to the case; never a multi-standard universal socket | Amish: "i approve your recommendations for all 555 open decisions." | REVIEW 2026-09-26, item 5 |
| 2026-10-02 | No window in the pack bay door | Amish: "i approve your recommendations for all 555 open decisions." | REVIEW 2026-09-26, item 2 |
| 2026-10-02 | Lit rocker main switch | Amish: "i approve your recommendations for all 555 open decisions." | REVIEW 2026-09-26, item 6 |

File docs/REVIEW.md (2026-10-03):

# Review note: PowerBox

## Session 2026-10-02 (later): approved follow-ups carried out

Amish approved on 2026-10-02 that every follow-up action from the open-decision sign-off be carried out. The 11 follow-up actions listed in the section below were worked through; 7 are done and 4 are not done (reasons given).

### Approved follow-ups carried out

1. Decision 1, appearance model to the constructable design: done. `cad/src/product_model.py` now has the lid with its 16 mm skirt and six side screws, corner tabs and rivets, handle base plates and bolts, 2 mm output and input panel plates, the plain door with hinge, cam latch and hasp over a staple, the 76 mm fan hole and four 8 mm feet, with dimensions read from `cad/src/model.py`. The render scenes were exported (below). The photoreal renders, card and social preview are made on Amish's Mac next.
2. Decision 2, door hinged on its front edge: done in the appearance model.
3. Decision 5, R2 target in `sizing.py`: done. The target is 1.8 evenings; the script was rerun and R2 now prints "Met" (1.87 evenings, 1.81 with minimum-capacity cells), matching PBX-CAL-001.
4. Decision 7, per-port energy and session counting in the host firmware notes: not done, because the host firmware is not written and firmware is TRL 4 work (on hold).
5. Decision 8, legacy-to-station question: not done here, because it is an action for the SwapCell project (listed under Cross-repo actions); the hold-up capacitor is only sized if the answer is no.
6. Decision 9, bare 5052 aluminium: done in the appearance model (body, lid and door are bare aluminium; no powder coat).
7. Decision 10, AC outlet cut-out for the national socket (model and making sketch): not done, because the first partner's country is not yet known; the 60 x 60 mm cut-out stays generic until it is.
8. Decision 10, name the national socket in BOM line 12: not done, for the same reason.
9. Decision 11, no window in the door: done in the appearance model.
10. Decision 12, lit rocker switch in BOM line 11: done. Line 11 is USD 47 (was USD 46); total USD 483.
11. Decision 12, switch cut-out check: done. The switch hole is now 22 x 30 mm with a 25 x 33 mm bezel (it was 21 x 26 mm, too small for a snap-in lit rocker). Four new constructability checks (bezel clear of the wake button and display, body in the plate, body clear of the lid skirt and inverter); all 68 checks pass.

### Key results

- Requirement status changes: R2 now prints Met in `sizing.py` and `results.csv` (documents already said met on paper). No other change.
- Value-engineering target: USD 450. Estimated cost of the constructable design: USD 483 (USD 33 over the target). Mass unchanged at 9.42 kg with the pack; overall size unchanged at 480 x 279 x 275 mm.
- Pictures regenerated: PBX-DWG-001 Rev P3; concept media (hero, blueprint, cutaway, exploded, flow, model.glb, viewer); the build plan overview, making sketches, hole layouts, joints, step pictures and wiring diagram from the updated model; the output panel sketch (PBX-DWG-110) and layout carry the 22 x 30 mm switch hole.
- Render scenes exported to `/home/claude/renders/powerbox`: hero, exploded and detail (one .npz and .json each, plus `powerbox__jobs.json`).
- Documents changed: PBX-CAL-001 v0.4, PBX-REQ-001 v0.7, PBX-PRC-001 v0.8, PBX-BLD-001 v0.3, PBX-DEC-001 v0.3, PBX-DDR-003 v0.3; `bom/bom.csv`, `bom/bom-notes.md`, `README.md`.

### Appearance deviations from model.py (Proposed, awaiting Amish)

Rivet and screw heads, the cam latch and its thumb-turn, the rocker switch lamp and the fan grille rings are drawn for realism and are not in the engineering model. The bench top was lowered 6 mm so the 8 mm feet stand on it.

### Cross-repo actions

- SwapCell (with MotionCore): decide whether a legacy-mode pack may be moved to station mode in use, and answer before PowerBox's interface is frozen; if no, PowerBox sizes a host hold-up capacitor.

### Not done

See items 4, 5, 7 and 8 above. TRL 4 remains on hold.

## Session 2026-10-02: open decisions decided by Amish

Amish wrote on 2026-10-02: "i approve your recommendations for all 555 open decisions." Every open decision in this repo's register was decided as recommended and moved to "Decisions made" in `docs/06-design-decisions.md`, dated 2026-10-02.

### Decisions recorded

12 decisions recorded (register items 1 to 12). The register's "Open decisions" section now reads: "None. All open decisions were decided on 2026-10-02."

### Documents changed

- `docs/06-design-decisions.md` v0.2
- `docs/decisions/0003-design-for-construction.md` v0.2
- `docs/decisions/0001-trl2-review-decisions.md` v0.3
- `docs/decisions/0002-recommendations-accepted.md` v0.2
- `docs/03-requirements.md` v0.6
- `docs/04-calcs/01-sizing.md` v0.3
- `docs/02-concept.md` v0.7
- `docs/01-problem.md` v0.5
- `docs/05-build-plan.md` v0.2
- `README.md` (R2 wording and DDR-003 status; not a controlled document)

PDFs re-rendered with `python3 .kit/render.py`. The CAD model, BOM quantities and prices, and pictures were not changed in that session (they were updated in the later session above).

### Follow-up actions to carry approved decisions into the design

1. Decision 1 (build plan pictures and renders): Update `cad/src/product_model.py` to the constructable design (lid skirt, runners, door with hinge, cam latch and hasp, panel plates, 76 mm fan hole, feet) and regenerate `media/render-*.png`, `media/card.png` and `media/social-preview.png` on Amish's Mac.
2. Decision 2 (build plan pictures and renders): Show the door hinged on its front edge in the appearance model and renders (they show a back-edge hinge).
3. Decision 5 (calculations): Change the R2 target in `docs/04-calcs/sizing.py` to 1.8 evenings and rerun, so that PBX-CAL-001 matches the hand-edited v0.3.
4. Decision 7 (documents): Add per-port energy and session counting, labelled approximate and not for billing, to the host firmware notes and display layout in `firmware/` when the host firmware is written.
5. Decision 8 (documents): Raise the legacy-to-station transition with the SwapCell project as one action shared with MotionCore; if the answer is no, size a hold-up capacitor for the host. SwapCell and MotionCore were not edited.
6. Decision 9 (build plan pictures and renders): Render the case as bare 5052 aluminium (the renders show powder coat), or caption the powder coat as a possible product finish.
7. Decision 10 (model): Size the AC outlet cut-out in the output panel plate for the first partner's national socket once the partner's country is known, in `cad/src/model.py` and the panel plate making sketch.
8. Decision 10 (BOM): Name the national socket type in BOM line 12 once the partner's country is known.
9. Decision 11 (build plan pictures and renders): Remove the window from the pack bay door in the appearance model and renders.
10. Decision 12 (BOM): Change the main switch in BOM line 11 to a lit rocker switch (about USD 1 more) and rerun the cost line.
11. Decision 12 (model): Check the switch cut-out in the output panel plate against the chosen lit rocker switch in `cad/src/model.py`.

### Points found in the review

- Item 5: R2 at 1.87 evenings is for typical cells; with minimum-capacity cells it is 1.81 (PBX-CAL-001), which none of the register's options mention.
- Item 9's recommendation to powder coat (from REVIEW.md 2026-09-26) did not consider that the case is the earth bond for the RCD; coating needs masked bond points.
- Item 8 is the same SwapCell question as MotionCore's (its 'To confirm' item 8); it should be tracked once with SwapCell.
- REVIEW.md 2026-09-26 items 1 (rubber feet) and 7 (grid charger size) are not in the register; item 1 is resolved by PBX-DDR-003, P12 (8 mm feet, height still within R10), and item 7 can be closed as render-only.
- Item 2's options repeat REVIEW.md 2026-09-26 item 3, which recommended the back edge; that recommendation is now superseded and should be marked so.

TRL 4 remains on hold by Amish's instruction.

## Session 2026-10-01: design for construction and prototype build plan (kit 1.7.0)

### What was done

- Kit 1.7.0 installed (`.kit/`, `.claude/commands/`); `CLAUDE.md` now matches `.kit/CLAUDE.md`.
- Constructability review of `cad/src/model.py` with build123d checks. The concept passed its clash check but could not be built: the lid sat on the wall edges, the pack floated 1 mm above its runners with nothing guiding its sides, the shelf, catch bracket and receptacle had no fixings, the door was a solid block, the panels had nowhere for the module bodies, and the protection parts had no place.
- `cad/src/model.py` rewritten as 45 components (`build_components()`), with 64 constructability checks (`python cad/src/model.py --check`), all passing, including a check that the pack slides out through the end opening. STEP and STL regenerated in `cad/step/` and `cad/stl/`.
- `docs/decisions/0003-design-for-construction.md` (PBX-DDR-003 v0.1, Draft): every change, made under Amish's 2026-09-30 instruction to make the design physically buildable; open for his review.
- `bom/bom.csv`: lines 1, 2, 3, 5, 6, 15, 16 and 18 repriced and respecified; `bom/bom-notes.md` updated.
- PBX-CAL-001 v0.2 (`docs/04-calcs/01-sizing.md`, `sizing.py`, `results.csv`): mass, size and cost of the constructable design; the budget reported as a value-engineering target. PBX-REQ-001 v0.5 and PBX-PRC-001 v0.6 follow.
- PBX-DWG-001 Rev P2 (`cad/src/sheets.py`); concept media regenerated (`media/hero.png`, `concept-blueprint`, `cutaway.png`, `exploded.png`, `flow.png`, `model.glb`, `viewer.html`).
- `cad/src/build_plan_media.py`: overview, 13 making sketches (PBX-DWG-101 to 113), 3 hole layouts, 11 joint close-ups, 15 step pictures and the wiring diagram (step 11), all drawn from the model.
- `docs/05-build-plan.md` (PBX-BLD-001 v0.1) and `docs/06-design-decisions.md` (PBX-DEC-001 v0.1).
- `project.yaml`: `design_state: constructable`; build plan, register, DDR-003, overview and the media script added to `trl_evidence`. README: links line and a "Building the prototype" section.

### Design changes made for construction (PBX-DDR-003)

1. Lid: the top rests on the walls and a 16 mm skirt hangs outside them with a 1 mm gap; six M4 screws into rivet nuts.
2. Handle: four M5 bolts through the lid and a 2 mm doubler plate.
3. Floor runners: four printed L-section lengths; the pack rests on them and the lips stand 1 mm off its sides; M4 screws from below into heat-set inserts. Top guide rail in two printed lengths screwed to the shelf.
4. Shelf: 2 mm folded aluminium (was a 4 mm slab), rear and end flanges riveted to the walls, front flange down, screwed to the catch bracket.
5. Catch bracket: 3 mm folded channel screwed to the floor and the shelf, catch bolted to its web.
6. Receptacle: on a 3 mm folded angle bracket screwed to the floor.
7. Door: 1.2 mm sheet on a piano hinge at its front edge, thumb-turn cam latch and padlock hasp and staple, in place of the magnetic catch that had no room.
8. Output and input panels: 2 mm plates over windows in the walls, four M4 screws each; the 12 V and barrel sockets moved up 15 mm to clear the inverter.
9. Protection plate for the main fuse, inverter breaker and relay; fuse block placed; floor holes for the inverter and converter; host on standoffs.
10. Riveted corner tabs on the folded tub.
11. Printed intake filter frame; the six exhaust slots behind the fan replaced by one 76 mm hole.
12. 8 mm self-adhesive rubber feet.

### Key results

- Mass 9.42 kg with the pack (was 8.61 kg); R10 met with 0.58 kg to spare. Overall 480 x 279 x 275 mm (was 482 x 276 x 278 mm).
- Value-engineering target: USD 450. Estimated cost of the constructable design: USD 482 (USD 32 over the target); the concept was USD 449.
- Requirement status otherwise unchanged: R2 not met (1.87 evenings), R6 at risk, R12 not verifiable at TRL 3, the rest met on paper.

### Proposed, awaiting Amish

All in the design decisions register (`docs/06-design-decisions.md`): accepting PBX-DDR-003 as a whole; the door hinge edge (front, as modelled, against the renders' back edge); theft resistance (thumb turn or keyed latch); the 0.58 kg mass margin; and the items carried over (R2, co-design partner, metering, SwapCell legacy-to-station question, finish, AC socket type, door window, lit switch).

### Safety concerns

- Unchanged from TRL 3: RCD function needs an inverter with an isolated, bondable output neutral; every 48 V fuse 60 V DC or more and 1 kA breaking; no back-feed; ventilation. New: the blade fuse block must be rated for the 48 V bus (58 V DC or more), and the 230 V wiring in the build plan is done or checked by a qualified electrician.

### Stale media (made on Amish's Mac)

The photoreal renders (`media/render-*.png`), `media/card.png`, `media/social-preview.png` and `cad/src/product_model.py` still show the concept lid, door (back-edge hinge, magnetic catch), panels and fan-end slots. They were not regenerated here and need updating with `/render-product`.

### Recommended next step

Amish to review PBX-DDR-003 and the open decisions in PBX-DEC-001. TRL 4 (buying parts and building to PBX-BLD-001) stays on hold.

## Session 2026-09-25: recommendations accepted

### Decisions applied

Amish wrote on 2026-09-25: "i accept all your recommendations, go with them across all repos." Every PowerBox item marked awaiting Amish that carried a recommendation is now "Decided by Amish, 2026-09-25: go with recommendation", recorded in `docs/decisions/0002-recommendations-accepted.md` (PBX-DDR-002 v0.1).

| Item | Before | After | Numbers |
| --- | --- | --- | --- |
| Recessed normally closed wake button in the INTERLOCK loop | Engineering proposal, awaiting Amish | Decided | No change; already in BOM line 11 and the model |
| 48 V to 12 V buck | 30 A proposed (20 A at TRL 2) | Decided at 30 A | 20 A (240 W) at TRL 2, 30 A (360 W) now, for 26.5 A demand; $30, already in the BOM |
| Fuse ratings | Proposed in PBX-CAL-001 Table 3 | Decided | 30 A main fuse, 60 V DC or more, 1 kA breaking; 20 A inverter breaker; unchanged |
| TRL 2 list items 1 to 8 and human-powered charging | Already decided in PBX-DDR-001 but still worded "Proposed, awaiting Amish" in this note | Wording updated below | None |

What changed: PBX-PRC-001 v0.4 to v0.5 (item 17 status and the fuse ratings in the key design choices); PBX-DDR-001 v0.1 to v0.2 (item 17 decided); PBX-DDR-002 v0.1 added; `project.yaml` trl_evidence lists DDR-002; README gains the concept rationale, burning platform, where it could be used and what sparked the idea sections. The budget stays at $450 (PowerBox parts, pack excluded). No requirement, calculation, BOM line, model geometry or drawing changed, because the accepted items were already designed in at TRL 3; PBX-CAL-001 stays at v0.1 and PBX-DWG-001 at Rev P1. All PDFs, drawing sheets and media were regenerated so the footer shows designmolecule.com.

### Requirement status (PBX-CAL-001, unchanged)

| ID | Result | Status |
| --- | --- | --- |
| R2 | 1.87 evenings per pack | **Not met** |
| R6 | 90.5 % worst case in the loss model | At risk |
| R11 | $449 against $450 | At risk |
| R12 | Swap time and display need users | Not verifiable at TRL 3 |
| R1, R3, R4, R5, R7, R8, R9, R10 | As in the TRL 3 session below | Met (R3, R7, R9 by design review) |

### Still awaiting Amish (no recommendation)

- R2 shortfall (PBX-DDR-001 item 13): relax R2, discharge to 3.5 %, or revise the reference evening with users.
- First co-design partner (item 14).
- Theft resistance, a lockable pack door (item 15).
- Energy metering for charging points (item 16).

### Cross-repo actions

- **SwapCell:** answer whether a pack in legacy discharge (state 5) may accept a station heartbeat and move to mode 2 or 4 without opening its output (PBX-DDR-001 item 18). PowerBox's host is powered from the pack and depends on this. Not changed locally.

### TRL 4

TRL 4 remains on hold by Amish's instruction. `trl: 3` and `trl_target: 3` are unchanged. Buying and wiring the fuses, buck and wake button, and any bench test, are TRL 4 and were not started.

## Session 2026-09-25: TRL 3

### What was done

- `docs/decisions/0001-trl2-review-decisions.md` (PBX-DDR-001 v0.1): Amish's 2026-09-25 decisions (items 1 to 12) and the items still open (13 to 18).
- `docs/04-calcs/01-sizing.md` (PBX-CAL-001 v0.1) with `docs/04-calcs/sizing.py` and `docs/04-calcs/results.csv`: energy, charging, converter efficiency, station mode and wake against SwapCell interface v0.3, outputs and pack current, fuses and pre-charge, standby, thermal, mass, cost and runtime, with a results table for R1 to R12.
- `cad/src/model.py`: parametric build123d model (case, lid, handle, SwapCell v0.3 pack envelope with plug, handle zone and latch pawl, bay with runners, top rail, class D catch and receptacle, door, electronics, panels, fan). Exports `cad/step/` and `cad/stl/` (assembly, enclosure, pack bay, reference pack) and runs a clash check (none found).
- `cad/src/sheets.py` and `cad/drawings/PBX-DWG-001.svg`, `.pdf`, `.png`: general arrangement at Rev P1, marked not for fabrication. PBX-DWG-001 was free because the concept blueprint uses PBX-DWG-010.
- `bom/bom.csv` (18 lines, every line priced with a supplier or supplier type) and `bom/bom-notes.md`.
- `cad/src/concept_media.py` now builds from `model.py`; all media regenerated (hero, blueprint, cutaway, exploded, flow, `model.glb`, `viewer.html`) and checked by eye; temporary `media/_views*` folders deleted.
- `docs/01-problem.md`, `docs/02-concept.md` and `docs/03-requirements.md` moved to v0.4 (they were already at v0.3 after the StepGen change on 2026-09-24), with decisions recorded, SwapCell interface v0.3 and numbers from PBX-CAL-001. The requirements table now has a status column.
- `project.yaml`: trl 3, trl_target 3, trl_evidence updated. `README.md`: TRL badge, budget scope, TRL 3 summary and key components. `budget_usd` stays at 450.

### Requirements (PBX-CAL-001)

| ID | Result | Status |
| --- | --- | --- |
| R2 | 1.87 evenings per pack (225 Wh per evening from the pack, 419 Wh usable) | **Not met** |
| R6 | 90.5 % at 12 V and 200 W in a loss model; 93 % or more elsewhere; MPPT stability not analysed | At risk |
| R11 | $449 of PowerBox parts against $450 | At risk |
| R12 | 30 s swap and status display by design; needs users | Not verifiable at TRL 3 |
| R1, R4, R5, R8, R10 | 419 Wh; 2.1 h grid; full in 0.70 solar day; 3.2 % per month off and 0.6 W ready; 8.6 kg and 482 x 276 x 278 mm | Met |
| R3, R7, R9 | Sources, outputs and back-feed rules | Met (design review) |

Corrections to TRL 2 numbers: the 48 V to 12 V buck was undersized (26.5 A needed, 20 A fitted; now 30 A); usable energy 421 to 419 Wh; a 5 % cut-off gives 1.97 evenings, not 2.0; mass 8.3 to 8.6 kg; PowerBox parts $435 to $449; pack price $370 to $414.

SwapCell interface v0.3 closes both TRL 2 interface issues: PowerBox's receptacle carries the 10 kΩ INTERLOCK coding resistor (item W), so a sleeping pack wakes without a keep-alive cell, and PowerBox is a station host (type 3) that requests mode 4 to charge while running loads (item C). The worst net charge current in station mode is 4.48 A, inside the 5.0 A limit. The bay uses a class D catch (item V).

### Decisions recorded (PBX-DDR-001)

Decided by Amish, 2026-09-25, go with recommendation: removable SwapCell pack (fixed LiFePO4 pack as fallback); horizontal side-loading bay; one DC input with MPPT; grid charging only through a certified external charger; 300 W AC outlet with auto-off and a documented DC-only variant; folded aluminium enclosure; 230 V 50 Hz with a 30 mA RCD first; budget kept at $450 for the PowerBox parts, excluding the pack (priced once in SwapCell); no human-powered input now. Cross-cutting approvals cited as SwapCell interface v0.3 items W, C and V.

### Still awaiting Amish (as of this session; see the 2026-09-25 recommendations session above for the current list)

- R2 shortfall: relax R2 to 1.87 evenings, discharge to 3.5 %, or revise the reference evening with users (about 189 Wh at the loads). No recommendation was made at TRL 2, so none is recorded as decided.
- First co-design partner (portfolio rule: chosen per area later).
- Theft resistance (lockable door) and energy metering for charging points.
- For SwapCell (not changed locally): may a pack in legacy discharge accept a station heartbeat and move to mode 2 or 4 without opening its output? PowerBox's host is powered from the pack and depends on this.

### Safety concerns

- RCD function depends on an inverter with an output isolated from its DC input, so its neutral can be bonded to the case and earth pin. Not yet confirmed from a datasheet.
- A short at the pack could draw about 496 A; every 48 V fuse needs a 60 V DC rating and at least 1 kA breaking capacity.
- In station mode PowerBox is a charger: the host must hold net charge at or below 5.0 A, especially when the fixed 5 A grid charger and solar are both connected.
- The wake button opens the INTERLOCK loop; pressed while running it drops the output, so it is recessed.
- Back-feeding through improvised double-male cords remains a user risk; labels and the guide must warn.
- About 60 W of heat at full load while charging needs the fan; not for closed cupboards or bags. Not for life-support equipment.

### Other notes

- No TRL 4 material exists in the repo (`build-log/` holds only its README; `electronics/` and `firmware/` are empty). None was created.
- No unchecked citations were listed; prior work in PBX-PRB-001 carries no links.

### Recommended next step

TRL 4 is on hold by Amish's instruction, so the next step is a decision, not a build: Amish to choose how to handle R2 and confirm the engineering proposals, and SwapCell to answer the legacy-to-station question. For the record only, TRL 4 would need a bench test article of the bay and receptacle, named inverter and charge controller parts with datasheets confirming neutral bonding and 90 % efficiency at 40 W and 12 V, a lab test report (TST, environment: lab) and build log entries.

## Session 2026-09-24: remove StepGen as a charging source

### What changed

- StepGen removed as a charging source in `project.yaml`, `README.md`, `docs/01-problem.md` (v0.3), `docs/02-concept.md` (v0.3), `docs/03-requirements.md` (v0.3) and `cad/src/concept_media.py`; media and `docs/pdf/` regenerated. Why: Amish decided on 2026-09-24 that StepGen becomes a walking-treadmill vehicle driven by a hub motor on a SwapCell pack, so it no longer generates power for PowerBox. A pack can still move between PowerBox and StepGen, as with SunSpoke.
- The DC input stays, with MPPT, for a solar panel, SunSpoke's panel or any 12 to 60 V DC source. R3 now lists solar and other DC sources; R6 is now "Use DC and solar input efficiently at low power" (90 % or more from 40 to 200 W, stable tracking). The StepGen rows in Table 2 and the human-power safety bullet are gone. Budget, TRL and other design content are unchanged.

### Decided (was proposed, awaiting Amish)

- **Human-powered charging in future.** Decided by Amish, 2026-09-25: go with recommendation (no human-powered input now; PBX-DDR-001 item 9). Options: (a) no human-powered input for PowerBox; (b) a pedal generator as a separate future repo that plugs into the existing DC input. Recommendation: not now; stay within the current scope.

## Session 2026-09-24: /populate to a strong TRL 2

### What was done

- `docs/01-problem.md` (PBX-PRB-001 v0.2): the problem, users and context (outage-prone homes, off-grid households, informal settlements, community charging points, repair shops), constraints, out of scope, prior work without links, open questions; co-design checklist kept.
- `docs/03-requirements.md` (PBX-REQ-001 v0.2): 12 measurable requirements (R1 to R12) with targets and planned verification, and a reference evening load profile (203 Wh at the loads).
- `docs/02-concept.md` (PBX-PRC-001 v0.2): how it works, components table numbered to the BOM and exploded view, first-order numbers with assumptions, runtime table, input and output specification, design choices, safety, open questions.
- `cad/src/concept_media.py`: massing model (aluminium case, lid, handle, SwapCell pack to the v0.2 envelope, pack bay and receptacle, bay door, charge controller, host controller, inverter, DC-DC converter, output panel, AC outlet, display, input panel, fan) with a table top and phone for scale.
- `media/`: hero, blueprint sheet (PNG and PDF), cutaway, exploded view with BOM callouts, energy flow diagram (estimates marked), `model.glb` and `viewer.html`.
- `bom/bom.csv`: 18 lines with indicative prices, numbered to match the exploded view; `bom/bom-notes.md`.
- `README.md`: hero image and links line added.
- `docs/pdf/`: branded PDFs of the three controlled documents.

### Key results (estimates, to be checked at TRL 3)

| Quantity | Estimate | Requirement |
| --- | --- | --- |
| Usable energy, one SwapCell pack | about 421 Wh (10 to 100 %) | R1 met |
| Reference evening (203 Wh at the loads) | 225 Wh from the pack; about 1.9 evenings per pack | R2 **not met** (target 2) |
| Grid charge, 10 to 100 % | about 2.1 h | R4 met |
| Solar, 200 W panel | about 635 Wh per clear day; full in one day | R5 met |
| Inverter idle if left on | about 190 Wh per day | Auto-off needed (R8) |
| Standby, ready | about 0.6 W | R8 met |
| Mass and size | about 8.3 kg with pack; 482 x 276 x 278 mm overall | R10 met, tight on height |
| PowerBox parts cost | about $435, excluding the SwapCell pack | R11 met, about $15 margin |
| Cost with one pack | about $805 | Above the $450 budget |

Requirements not met or at risk: R2 is missed by about 5 %; R6 is at risk until a converter is chosen and its efficiency at 40 W is known; R11 is met only because the pack is excluded.

### Proposed at TRL 2; status after 2026-09-25

Items 1 to 8 are now "Decided by Amish, 2026-09-25: go with recommendation" (PBX-DDR-001 items 1 to 8). Items 9 and 10 had no recommendation and remain "Proposed, awaiting Amish".

1. Removable SwapCell pack (recommended), with a fixed internal 12.8 V LiFePO4 pack (about 384 Wh, about $110) kept as a documented fallback.
2. Horizontal side-loading pack bay with an end door, rather than a tall top-loading bay.
3. One DC input with MPPT for solar and SunSpoke's panel; a second input later if users need both at once (about $30 more).
4. Grid charging only through a certified external 54.6 V, 5 A charger brick; no AC inlet on the box.
5. Include the 300 W AC outlet with auto-off, and document a DC-only variant (saves about $92, no mains voltage).
6. Folded aluminium enclosure over a rugged plastic case.
7. AC region first: 230 V 50 Hz with a 30 mA RCD.
8. Budget: keep $450 for PowerBox parts excluding the pack (recommended), or raise to about $850 to include one pack. `project.yaml` is unchanged at $450.
9. R2 shortfall (still proposed, awaiting Amish): accept 1.9 evenings, allow discharge to 5 % (about 2.0 evenings, more cell wear), or revise the load profile with users.
10. First co-design partner (still proposed, awaiting Amish): an NGO running community charging points, a solar home system distributor, or a university group in an outage-prone city.

### Interface issues to raise with SwapCell (not changed locally)

- **Waking the pack.** WAKE needs 5 to 15 V from the host, but a battery-only host like PowerBox has no source when the pack is asleep and no charger is connected. Options: a keep-alive cell in PowerBox, wake on interlock closure, or a wake button on the pack.
- **Pass-through.** The v0.2 behavior rules allow charging only with a dock heartbeat and define no host that charges and discharges at once. PowerBox needs a "station" host type with a combined mode to run the router while charging from solar.

### Safety concerns

- Back-feeding: the box has no AC inlet and grid charging is DC only, but users can still improvise double-male cords. Labels and the user guide must warn clearly.
- GFCI or RCD on an inverter output only works if the output neutral is bonded to the case and earth; many small inverters float. This must be confirmed for the chosen inverter.
- A 468 Wh lithium-ion pack in a living space: fused, BMS-protected, charged on a non-combustible surface, with ventilation and temperature cut-offs. The charge controller sits on a shelf above the pack; its heat path needs checking.
- Inverter heat (about 41 W at full load) needs the fan; the box must not be used in a closed cupboard or bag.
- PowerBox must not be relied on for life-support equipment.

### Recommended next step

Review this note and the media. If approved, run `/advance-trl3` to size the converters, inverter and fuses by calculation, confirm the inverter's GFCI or RCD compatibility and idle draw, settle the SwapCell wake and pass-through questions with the SwapCell design, and produce the parametric model and drawing sheet.

## Session 2026-09-26: product appearance model and photoreal renders

Amish chose this repo for the first batch of product renders on 2026-09-26. This session adds an appearance model for photoreal, product-style renders. It changes no requirement, calculation, BOM line, drawing or `cad/src/model.py`.

### What was added

- `cad/src/product_model.py`: `product_parts()` returns 82 parts (46 shell, 20 internal, 4 accessory, 12 context), each with a colour, a render material, a BOM line and an explode offset. It imports `PARAMS`, `pack_frame()` and the model.py geometry, so every main dimension and interface is unchanged (460 x 260 x 220 mm case, 12 mm lid, SwapCell v0.3 pack envelope, plug, handle, latch pawl, bay, receptacle and all panel and component envelopes). model.py has no `derived()`; `pack_frame()` plays that role.
- Appearance detail: filleted case and lid corners with a parting-line groove at the lid joint; stadium exhaust slots and four lid screws; folding handle with hinge posts, ferrules and a ribbed rubber grip; output panel with USB-C PD and USB-A ports, 12 V car socket and barrel jack, rocker main switch with a lit indicator, the recessed wake button, printed port marks and a teal accent band; display with a lit state-of-charge readout; AC outlet module with socket recess, earth clips, RCD test and reset buttons and a lit status light; Anderson PP45 input panel with red and black housings and printed marks; pack bay door with a clear window onto the SwapCell pack, pull, padlock eye, hinge knuckles and catch strip; ringed fan grille; rubber feet; name plate.
- Internals for the exploded view: filleted SwapCell pack with lid-face ribs, label, plug, rubber handle and latch pawl; bay runners, rail, shelf, catch bracket and receptacle; finned charge controller; host board with ESP32 shield and relays; finned inverter and buck converter; fan; intake dust filter.
- Accessory: the grid charger brick (BOM 17) with its Powerpole DC lead, shown only in the exploded view.
- Context: a compact oak bench top, a small solar panel on a folding stand behind the case wired to the DC IN Powerpole, and a phone charging from USB-C.
- `TITLE` and `RENDER_VIEWS`: hero (front right, 30 deg elevation, with context), exploded (front right, 28 deg) and detail (front, 12 deg, shell only, framing the output panel).
- README hero image now points to `media/render-hero.png` with a link to `media/render-exploded.png`. The render files are produced later by the orchestrator.

### Differences from model.py (each Proposed, awaiting Amish)

1. **Rubber feet.** Four 2 mm rubber feet (BOM 18) sit under the case floor, so the overall height becomes 280 mm and uses the 2 mm spare in R10. Recommendation: recess the feet into dimples in the folded floor so R10 keeps its margin.
2. **Window in the pack bay door.** The door (BOM 6) has a 26 x 76 mm clear polycarbonate window so the pack is visible. It is not in model.py or the BOM. Recommendation: keep it as a render option only until TRL 4; a window adds cost and a sealing detail.
3. **Door hardware.** The padlock eye is a separate tab beside the pull (model.py folds it into the pull block), and the hinge knuckles are drawn on the back edge of the door (model.py does not say which edge). Recommendation: hinge on the back edge so the door opens toward the user at the front.
4. **Finish and colour.** The case is shown powder-coated light grey with a dark lid, dark panels and a teal accent. The BOM gives bare 5052 aluminium. Recommendation: powder coat, priced within the BOM 1 and 2 lines at TRL 4.
5. **AC socket type.** The 230 V outlet is drawn with a round, earth-clip recess (CEE 7/3 style). The BOM does not name a socket type. Recommendation: choose the socket type with the first co-design partner's country.
6. **Lit main switch.** The rocker main switch carries a lit indicator; BOM 11 names a plain main switch. Recommendation: accept, since a lit switch shows the box is on and costs little.
7. **Grid charger size.** The charger brick is drawn at 170 x 72 x 42 mm, an assumption; model.py does not model BOM 17.

Powerpole housings, USB ports and sockets are drawn inside the model.py envelopes at appearance scale, not at connector-datasheet dimensions.

### Scope

This is an appearance model only, with no tolerances and no fabrication detail. `trl` stays 3, `trl_target` stays 3, and TRL 4 remains on hold.

## Session 2026-09-27: kit 1.5.0 and image quality

- Kit 1.5.0 synced: STANDARDS v1.5 (sections 12 to 15: product renders, storefront images and image quality, public release, authorship and signing), `.kit/cards.py`, `.kit/image_qc.py`, `.kit/release_gate.py`, issue templates, and the `/render-product` and `/release` commands. `CLAUDE.md` now matches `.kit/CLAUDE.md`.
- Every `media/render-*.png` recaptioned from its original render with the new layout: the title, concept label and repository sit in a band above the render and the view note in a band below it, each line wrapped to the image width, so no text overlaps other text or the render or runs off the image. `media/card.png` and `media/social-preview.png` regenerated with the same rules.
- `python .kit/image_qc.py` and `python .kit/release_gate.py` pass. trl stays 3.

## 2026-10-02: photoreal renders redone on the constructable design

Rendered with Blender Cycles on Amish's Mac from the updated appearance model; captioned with `.kit/photo_caption.py`; `media/card.png` and `media/social-preview.png` regenerated with `.kit/cards.py`. Views: hero, exploded, detail. image_qc passes. Appearance deviations are those logged above as proposed, awaiting Amish.

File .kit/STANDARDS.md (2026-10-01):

---
doc_id: OHP-STD-001
title: Documentation and drawing standard
project: Open Hardware Portfolio
doc_type: Standard
version: "1.7"
status: Released
date: 2026-09-30
author: Amish Chadha
license: CC-BY-SA-4.0
revisions:
  - version: "1.0"
    date: 2026-09-24
    author: Amish Chadha
    change: First release of the standard
  - version: "1.1"
    date: 2026-09-24
    author: Amish Chadha
    change: Adopt Technology Readiness Levels (section 9) for project maturity
  - version: "1.2"
    date: 2026-09-24
    author: Amish Chadha
    change: Portfolio phase cap (section 10), concept media standard (section 11), CLAUDE.md guardrails
  - version: "1.3"
    date: 2026-09-24
    author: Amish Chadha
    change: Scale figure, interactive 3D viewer and flow diagrams added to concept media; session slash commands
  - version: "1.4"
    date: 2026-09-26
    author: Amish Chadha
    change: Every sheet and render names the project and its GitHub repository; overall dimensions, ISO centre lines and 300 dpi PNG on sheets; titles name the device and view labels state the viewing direction; optional photoreal renders with Blender
  - version: "1.5"
    date: 2026-09-27
    author: Amish Chadha
    change: Product renders (section 12), storefront images and image quality check (section 13), public release and release gate (section 14), authorship, citation and commit signing (section 15)
  - version: "1.6"
    date: 2026-09-29
    author: Amish Chadha
    change: Licensing metadata with REUSE (section 16), Zenodo DOI and Software Heritage archiving (section 17), release gate checks REUSE and a single CITATION.cff license, archive.py
  - version: "1.7"
    date: 2026-09-30
    author: Amish Chadha
    change: Concept and constructable design states; design decisions register (DEC) kept apart from the build plan; prototype build plan (BLD, section 18) with pictures by component is required TRL 3 evidence; every repo targets TRL 3 during the populate phase; build_views.py; /to-trl3 and /build-plan commands
---

# Documentation and drawing standard

Every project in the portfolio uses this standard, so that each precis, write-up and sketch looks the same and carries its own version history. The standard ships as a kit in each repo's `.kit/` folder. The kit version is in `.kit/KIT_VERSION`.

## 1. Document types and IDs

Every controlled document has a unique ID in the form `PRJ-TYP-NNN`.

- `PRJ` is the three-letter project code listed in section 7.
- `TYP` is the document type code from the table below.
- `NNN` is a sequence number within that project and type, starting at 001.

| Code | Type | Typical file |
| --- | --- | --- |
| PRC | Design precis | `docs/02-concept.md` |
| PRB | Problem statement | `docs/01-problem.md` |
| REQ | Requirements | `docs/03-requirements.md` |
| CAL | Calculation or sizing note | `docs/04-calcs/*.md` |
| DDR | Design decision record | `docs/decisions/*.md` |
| BOM | Bill of materials | `bom/bom.csv` |
| DWG | Drawing or sketch sheet | `cad/drawings/*.svg` |
| BLD | Prototype build plan (section 18) | `docs/05-build-plan.md` |
| DEC | Design decisions register (section 18) | `docs/06-design-decisions.md` |
| TST | Test plan or test report (front matter adds `environment: lab` or `relevant`) | `docs/05-tests/*.md` |

Example: `TBK-PRC-001` is the ThermaBrick design precis.

## 2. Revision scheme

| Artifact | While in draft | When released | Change after release |
| --- | --- | --- | --- |
| Documents | 0.1, 0.2, 0.3 ... | 1.0 | 1.1 for minor edits, 2.0 for a design change |
| Drawings | Rev P1, P2 ... (preliminary) | Rev A | Rev B, C ... |

- Every change to a controlled document adds a row to its revision history before the commit.
- The `version` field in front matter always equals the newest row in `revisions`. The renderer rejects a document where they differ.
- Status is one of `Draft`, `In review`, `Released` or `Superseded`. Draft and In review documents print with a status band on every page.
- Every release is tagged in Git as `<doc_id>/v<version>`, for example `TBK-PRC-001/v1.0`. Drawings are tagged `TBK-DWG-001/revA`.
- Git history is the full audit trail. The in-document revision table is the human-readable summary.

## 3. Document front matter

Every Markdown document under version control starts with this block:

```yaml
---
doc_id: TBK-PRC-001
title: ThermaBrick design precis
project: ThermaBrick
doc_type: Precis
version: "0.1"
status: Draft
date: 2026-09-24
author: Amish Chadha
license: CERN-OHL-S-2.0
revisions:
  - version: "0.1"
    date: 2026-09-24
    author: Amish Chadha
    change: Initial draft
---
```

Quote version numbers so YAML keeps `1.0` as text instead of turning it into a number. List revisions newest last.

## 4. Writing style

- Chicago Manual of Style.
- No em dashes. Restructure the sentence instead.
- Lead each section with its conclusion, then support it.
- SI units throughout, in the form `12 kW`, `450 °C`, `3.2 m`. Imperial values may follow in parentheses.
- Number every figure and table ("Figure 2", "Table 1") and give each a caption.
- State every assumption in the calculation that depends on it.
- Put safety notes in a blockquote starting with **Safety:**.

## 5. Visual identity

| Element | Specification |
| --- | --- |
| Typeface | IBM Plex Sans for text, IBM Plex Mono for code and values (SIL Open Font License, bundled in `.kit/fonts`) |
| Ink | `#111827` |
| Secondary text | `#4B5563` |
| Rules and grid | `#D1D5DB` |
| Accent (one only) | `#0F766E` teal |
| Document page | US Letter, 20 mm margins |
| Drawing sheet | ANSI B landscape (431.8 x 279.4 mm) |
| Footer | Document ID, version, status, license and designmolecule.com on every page |

## 6. Drawing and sketch conventions

- Units are millimeters unless the title block says otherwise.
- Third-angle projection, marked with the symbol in the title block.
- Line weights: visible outlines 0.5 mm, hidden lines 0.25 mm dashed, center lines 0.18 mm chain.
- The title block contains the project, title, drawing number, revision, scale, units, projection, sheet, author, date, material or notes, and license.
- Every sheet and every render names the project and its GitHub repository (from `repo:` in `project.yaml`), at the top of the sheet and in the title block, so a printed or forwarded sheet is never anonymous.
- The drawing title names the device, not only the drawing type (for example "Handheld near-infrared resin scanner: general arrangement").
- Every view label states its scale and viewing direction (for example "Scale 1:1; side elevation looking along +Y"), and every isometric or render states where it is seen from.
- Orthographic views generated with `add_ortho` carry overall dimensions (length and depth on the top view, height on the front view) and ISO 128 centre lines on cylinders; hidden lines are dashed. Tolerances are not shown before TRL 4.
- Sheets are exported as SVG, PDF and a 300 dpi PNG.
- The revision table in the top right of the sheet lists every revision.
- Concept sketches use the same sheet and title block and carry the label "CONCEPT, NOT FOR FABRICATION".
- Geometry comes from `cad/src/*.py` (build123d). Sheets are generated by `.kit/drawing.py` and never edited by hand.

## 7. Project codes

| Code | Project | Code | Project | Code | Project |
| --- | --- | --- | --- | --- | --- |
| TBK | ThermaBrick | PCF | PicoFlow | HLT | HelioLite |
| CCB | CharCube | DRN | DustRunner | TRT | TremorTrace |
| STC | StepCue | FXH | FlexHand | CPD | ColdPod |
| SCL | SunClave | STR | SteamRoot | GGD | GrainGuard |
| SDL | SeedLine | ZBX | ZeerBox | RMS | RootMesh |
| DWD | DewDrive | SSK | StillStack | PPR | PotPress |
| WWT | WaterWatch | LMF | LumaFlow | FCL | FieldCell |
| CNP | ConePro | CVC | CulvertCrawl | EGD | EmberGuard |
| SNF | SnapFrame | CGM | CargoMule | SCM | StepClimber |
| SWC | SwapCell | PLP | PalletPilot | FTK | FlatTrike |
| WWK | WaterWalker | GRR | GrowRider | SSP | SunSpoke |
| SGN | StepGen | PBX | PowerBox | WML | WasteWise-ml |
| WSC | WasteWise Scan | RFE | ReflowEconomy | | |
| OHP | Portfolio-wide | | | | |

## 8. Build and publish

- `python .kit/render.py` checks every controlled document and renders it to `docs/pdf/<doc_id>_v<version>.pdf`.
- `python .kit/drawing.py` (called from each project's `cad/src/sheets.py`) builds drawing sheets as SVG and PDF in `cad/drawings/`.
- The GitHub Action in `.github/workflows/docs.yml` runs the checks on every push and attaches PDFs to a GitHub Release whenever a release tag is pushed.
- Public releases follow section 14: `python .kit/release_gate.py` must pass, and the release tag is `v0.<TRL>.0` (for example `v0.3.0` at TRL 3).

## 9. Technology Readiness Level (TRL)

Each project states its maturity as a Technology Readiness Level on the NASA and US DOE 1 to 9 scale. The TRL rates this specific design, not the underlying technology. A sand battery is commercial elsewhere, but a new sand battery design starts at TRL 2 until evidence shows otherwise.

| TRL | Definition | Evidence the repo must contain |
| --- | --- | --- |
| 1 | Basic principles observed | Problem statement (PRB) |
| 2 | Technology concept formulated | Draft precis (PRC) and requirements (REQ) |
| 3 | Analytical or experimental proof of concept | Calculation note (CAL), working build123d model with STEP export, drawing sheet (DWG), priced BOM with every unit cost filled in, prototype build plan (BLD) with pictures, `design_state: constructable` |
| 4 | Components validated in the lab | Test report (TST) with `environment: lab`, build log entries |
| 5 | Validated in a relevant environment | Test report (TST) with `environment: relevant` |
| 6 | System prototype demonstrated in a relevant environment | Precis at version 1.0 or later with status Released, a drawing at a lettered revision (Rev A or later), and a system-level TST with `environment: relevant` |
| 7 to 9 | Operational demonstration through proven in service | Beyond portfolio scope; claim only with a named deployment partner and evidence |

Rules:

- `project.yaml` records `trl` (current level), `trl_target` (the level the current effort aims for) and `trl_evidence` (the files that support the claim).
- `python .kit/render.py --check` fails if the evidence for the claimed TRL is missing. CI runs this check on every push.
- Documentation alone cannot go past TRL 3. TRL 4 and above require hardware and a test report.
- TRL and visibility are independent. A repo can be public at TRL 3 as a documented design ready to build.
- A change of TRL is recorded in the build log with the date and the evidence that justified it.

## 10. Portfolio phase and TRL cap

`.kit/PHASE.yaml` sets the current phase. During the **populate** phase every repo is capped at **TRL 3**: `trl` and `trl_target` may not exceed 3, and the check fails if they do. Every repo targets the cap: `trl_target` must equal 3, so a new repo is taken all the way to TRL 3 (scaffold, populate and advance, see `/to-trl3`). Work that belongs to TRL 4 or later (building or testing hardware, test articles, test plans and reports, build-log entries, purchasing lists, PCB layouts) must not be started. The prototype build plan (BLD, section 18) is TRL 3 paper work and is required. Where it already exists it is kept, flagged in the check output, and not extended. Only Amish changes `PHASE.yaml`.

Every repo carries a `CLAUDE.md` with the working rules for AI sessions: the TRL cap, decision rights (nothing is recorded as decided unless Amish decided it), one step per session, and a mandatory `docs/REVIEW.md` before stopping.

## 11. Concept media

Every repo at TRL 2 or above explains its idea visually. Media are generated from a build123d massing model with `.kit/concept.py`, never drawn by hand, so they stay in step with the design.

| File | Required | Purpose |
| --- | --- | --- |
| `media/hero.png` | TRL 2+ | Shaded isometric render with a 1.75 m person for scale; the website card image |
| `media/concept-blueprint.png` and `.pdf` | TRL 2+ | Blueprint concept sheet: orthographic and isometric views, scale, key figures, title block |
| `media/model.glb` and `media/viewer.html` | TRL 2+ | Interactive 3D viewer (glTF plus model-viewer) for the website |
| `media/cutaway.png` | When the inside matters | Section view showing internal parts |
| `media/exploded.png` | Recommended | Exploded view with numbered callouts matching the BOM |
| `media/flow.png` | When energy or material moves | System, energy or material flow diagram with losses |

Session commands in `.claude/commands/` (`/populate`, `/advance-trl3`, `/rein-in`, `/refresh-media`) carry the standard prompts, so every Claude Code session starts from the same instructions.

At TRL 2 a massing model is enough: correct overall proportions and main components. All concept media carry "CONCEPT, NOT FOR FABRICATION". The check warns when required media are missing at TRL 2 and fails at TRL 3.

## 12. Product renders

Every repo at TRL 3 shows the product as it would look, not only as a massing model.

- `cad/src/product_model.py` is the appearance model. It defines `product_parts()` (named parts with a shape and a material), `TITLE` ("Name: what it is") and `RENDER_VIEWS`. It is for renders only: every main dimension comes from `cad/src/model.py`, never typed in again.
- Where the appearance model departs from `model.py` (a chamfer, a label, a fastener drawn for realism), record the deviation in `docs/REVIEW.md` as "Proposed, awaiting Amish".
- Scale comes from context, not from a floating figure: a hand or forearm for handheld objects, and the posed mannequin (`mannequin()` in `.kit/context_parts.py`: stand, walk, push, ride, sit, reach) for anything a person uses at body scale.
- Renders are made with `.kit/export_views.py` (one scene per view) and `.kit/photoreal.py` (Blender Cycles), then captioned with `.kit/photo_caption.py`. Files are `media/render-<view>.png`; `media/render-hero.png` is required.
- Every caption names the project, the repository and the viewing direction, and carries "CONCEPT, NOT FOR FABRICATION".
- Captions never sit on the render. `.kit/photo_caption.py` adds a header band (title, concept label, repository) above the render and a footer band (view note) below it, wraps every line to the image width, and steps the font down to a floor before adding a line.
- The README opens with `media/render-hero.png`.
- Software-only and scene repositories (no single product) may use a scene render as the hero instead of a product model.

## 13. Storefront images

Two images, both made from `media/render-hero.png` by `python .kit/cards.py .`:

| File | Size | Purpose |
| --- | --- | --- |
| `media/card.png` | 800 x 800 | Square thumbnail for the organization profile page |
| `media/social-preview.png` | 1280 x 640, under 1 MB | GitHub social preview, shown when a repository link is shared |

- The social preview shows the area, name, one-line description, the first sentence of the pitch, the brand line and the repository address. Design Molecule repos read "Design Molecule · open hardware concept, TRL n"; OpenRatio repos read "OpenRatio · research and educational prototype, TRL n".
- GitHub has no API for the social preview. Upload it under the repository's Settings, Social preview, on release day.
- Regenerate both images whenever `render-hero.png` changes.

### Image quality

Every render, card and social preview must be clear and readable. `python .kit/image_qc.py` checks each one, and the release gate blocks on any failure:

| Check | Rule |
| --- | --- |
| Layout | Made by the current `photo_caption.py` or `cards.py`, which store the text layout in the PNG |
| Text inside the image | Every line at least 1.2 % of the image width from each edge; nothing runs off the side |
| No overlap | No line of text touches another line, and no caption text sits on the render |
| Text size | Render captions at least 1.05 % of the image width in pixel height (17 px at 1600 px); social preview text at least 16 px |
| Resolution | Renders at least 1200 px wide; card 800 x 800; social preview 1280 x 640 and under 1 MB |
| Sharpness | The render is not blurred or upscaled (edge sharpness at least 15 on the `image_qc.py` scale) |

Long titles and notes wrap to more lines rather than shrinking below the floor. The social preview shortens the pitch sentence with an ellipsis only if it cannot fit at the smallest size.

## 14. Public release

A repository goes public only when Amish approves it, and only after `python .kit/release_gate.py` passes. The gate checks:

1. `render.py --check` passes (document control, TRL cap, concept media).
2. Storefront: hero render, card, social preview under 1 MB, README leading with the hero, and every image passing the image quality check (section 13).
3. Issue templates in `.github/ISSUE_TEMPLATE/`: question, build report, design suggestion. The build report template restates that the design is a TRL 3 concept, not released for fabrication (OpenRatio: a research and educational prototype, not a medical device).
4. `CITATION.cff` valid, with an author ORCID.
5. License files match `project.yaml`.
6. No em dashes in the repository's own text.
7. BioMedical and OpenRatio repos use soft, non-clinical wording: "research and educational prototype, not a medical device".
8. No secrets anywhere in the history (gitleaks).
9. No links to sibling repositories that are still private.
10. REUSE files present (`REUSE.toml`, `LICENSES/`, `.github/workflows/reuse.yml`) and `reuse lint` passes (section 16).
11. `CITATION.cff` names exactly one license, because Zenodo rejects a list (section 17).

It warns, without blocking, when the README lacks a Safety heading or a "not for fabrication" statement, when `CITATION.cff` has no DOI yet, and when the README lacks the Zenodo DOI, REUSE or Software Heritage badge, so a person can confirm.

On release day, per repository:

- A signed, annotated tag `v0.<TRL>.0` on `main`.
- A GitHub release with short notes (what it is, TRL, status, licenses, how to cite) and a design pack, `<repo>-v0.<TRL>.0-design-pack.zip`, holding `cad/step`, `cad/drawings`, `docs/pdf`, `bom`, README, licenses and `CITATION.cff`.
- Description from the first sentences of `pitch` (350 characters at most), website `https://designmolecule.com` (OpenRatio: `https://openratio.ai`), topics from `project.yaml`.
- Before the first release, the repository is switched on in Zenodo (section 17), so the release is archived and gets a DOI.
- Visibility switched to public last, after the release exists.
- The social preview uploaded and the organization profile updated with the new cards.
- After the release: the concept DOI written to `CITATION.cff` and a Software Heritage save requested (section 17).

The internal working files (`CLAUDE.md`, `.kit/CLAUDE.md`, `.claude/commands/`, `docs/REVIEW.md`) stay public, and open "Proposed, awaiting Amish" items stay visible as open questions (Amish, 2026-09-27).

## 15. Authorship, citation and signing

- Amish Chadha is the author of every design, ORCID 0009-0000-8079-7141. Commits are authored as Amish Chadha <amish@designmolecule.com>.
- `CITATION.cff` lists Amish (with ORCID) first, then any credited contributors; `CONTRIBUTORS.md` and the README Credits section agree with it.
- `CITATION.cff` names one license: the hardware license (CERN-OHL-S-2.0), or the software license in a software-only repository. The full split between hardware and software licenses lives in `REUSE.toml` and the README. Once the repository is archived, `CITATION.cff` carries the concept DOI in `doi:`.
- Work done with Claude carries the trailer `Co-Authored-By: Claude <noreply@anthropic.com>` (with the model name), and the README Credits section says designs are developed with AI assistance.
- Every commit and tag pushed to GitHub is signed with Amish's SSH signing key, so GitHub shows it as Verified. Commits prepared elsewhere are re-signed on Amish's Mac before they are pushed.
- Once a repository is public, its history is never rewritten.

## 16. Licensing metadata (REUSE)

Every file states its copyright and license in a machine-readable way, following the REUSE Specification 3.3 (https://reuse.software). A repository is set up with:

```
python .kit/archive.py reuse
```

This writes three things and adds the REUSE and Software Heritage badges to the README badge line:

- `REUSE.toml`, built from the licenses in `project.yaml`. Everything is under the hardware license by default. Scripts, firmware, notebooks, web viewers, workflows and agent commands are under the software license. `cad/` and `electronics/` stay under the hardware license even where they are written as Python. The bundled IBM Plex fonts are OFL-1.1 (IBM Corp.). Copyright is "<first commit year> Amish Chadha".
- `LICENSES/`, with the full text of each license used (`reuse download`). The root `LICENSE` and `LICENSE-SOFTWARE` files stay for GitHub's license detection.
- `.github/workflows/reuse.yml`, which runs the REUSE check (fsfe/reuse-action) on every push and drives the README badge.

A new kind of file that falls outside these rules gets a new annotation in `REUSE.toml` rather than a header comment. `reuse lint` must pass before every commit that adds files, and the release gate enforces it.

## 17. Archiving and DOI (Zenodo and Software Heritage)

Every public repository is archived twice, so the design stays citable and retrievable if GitHub changes.

Zenodo (a citable DOI for each release):

1. Amish's Zenodo account is linked to GitHub. Before the first release, Amish switches the repository on in Zenodo (Account, GitHub). Only Amish changes Zenodo or GitHub settings.
2. Run `python .kit/archive.py zenodo`: it makes sure `CITATION.cff` names one license and adds the Zenodo DOI badge, which uses the GitHub repository ID and always points at the latest version. Zenodo reads its metadata (title, authors with ORCID, license, keywords) from `CITATION.cff`, and rejects the whole archive when that file lists several licenses.
3. Publish the GitHub release (section 14). Zenodo archives it within minutes and mints two DOIs: a version DOI for that release and a concept DOI that stands for all versions.
4. Check the Zenodo record: title, author and ORCID, license, keywords. If Zenodo shows "Citation metadata load failed", fix `CITATION.cff`, validate it with cffconvert and publish a new patch release (for example `v0.3.2`); a failed release is never re-used.
5. Run `python .kit/archive.py zenodo --doi <concept DOI>` and commit, so GitHub's "Cite this repository" and every future archive carry the concept DOI. Every later release gets its own version DOI automatically; the concept DOI never changes.

Software Heritage (permanent source archive):

1. After the repository is public, request a save at https://archive.softwareheritage.org/save/ (origin type git, the repository URL). Anonymous requests are limited to about ten an hour, so batches are spread out.
2. The Software Heritage badge on the README resolves once the save is accepted and ingested. Later pushes are picked up by its regular crawl.

OpenRatio repositories follow the same steps when Amish approves their release.

## 18. Prototype build plan (BLD) and the constructable design

### Two design states

A design moves through two states, recorded as `design_state` in `project.yaml`:

- **Concept**: the design shows what the product does and that it works on paper (TRL 2 and the calculations of TRL 3). Parts may be simplified shapes that have never been checked for how they are made or how they join.
- **Constructable**: every part can be made with the stated process and material, and every part fits and fastens to the parts next to it. Nothing is left as a shape that cannot be cut, cast, bent, printed, machined or bought.

A repo reaches TRL 3 only when its design is constructable and its build plan shows how. Writing the build plan is how the design is made constructable: when a part cannot be made or cannot fit as modelled, change the model so it can (Amish, 2026-09-30: "fix the design assumptions to match and be physically feasible"), keep what the concept does, and record every change in a decision record "Design for construction" (DDR) and in the plan. Changes that alter what the product does, its pitch or its safety case are proposed, not made.

### What the build plan is

`docs/05-build-plan.md` (`PRJ-BLD-001`) tells a capable maker how to build the first proof-of-concept prototype, in order, component by component, and shows it in pictures. It is written before anything is built, states "Plan, not yet built" under the title and never claims results. Building and testing to it is TRL 4 work.

### Writing rules

- **Plain English.** Say "the steel plate the jack stands on", not a model parameter or variable name. No code identifiers, function names, parameter names or file paths in the body of the plan. Give sizes as numbers with units ("a 62 mm hole, centred 100 mm up from the bottom edge"). The only place file names appear is the closing "Where the numbers come from" list.
- **Pictures first.** Every component and every assembly step has a picture. A reader should be able to build from the pictures, with the words explaining what the pictures cannot show (order, force, tolerance, checks).
- **By component, in build order.** Each component is made and checked before the step that needs it.
- **Cost is not the focus.** One line in the overview may state the parts cost from the BOM; there is no cost or time section.

### Sections, in order

1. **What you are building**: the overview picture (every component pulled apart and numbered in build order) and one short paragraph.
2. **What changed to make it buildable**: a table of each change from the concept (what the concept had, what the constructable design has, why), with a picture where the change is visible. "None" if nothing changed.
3. **Making the components**: one subsection per made component, in build order, each with:
   - its making sketch (three views with overall sizes, a 3D view, where it goes, making notes), `cad/drawings/PRJ-DWG-1NN`;
   - what it is and what it is made from (material, stock size);
   - how to make it, as numbered steps (mark out, cut, drill, bend, weld, cast, print, machine, finish), with the sizes that matter;
   - how it fits the parts next to it: a close-up picture of the joint, which faces touch, what holds them (bolt, weld, pin, clip, glue), the gap or fit needed, and which side goes where;
   - the check before moving on.
   Bought components get a short subsection: what to buy (specification, not brand), and what to do to it (drill, trim, fit).
4. **Putting it together**: numbered assembly steps, each with a step picture (parts already fitted in grey, the part being fitted in colour with an arrow showing the way it goes in), the fasteners, and any hold point.
5. **First checks**: fit, movement, first power or first load, each tied to a requirement ID with a pass criterion. The plan lists them; a TRL 4 test report records them.
6. **Safety stops**: points where work stops (before energising, pressurising, loading, lifting or operating) and what must be true to carry on.
7. **Tools, skills and workspace.**
8. **Where the numbers come from**: the model, drawings, calculation note and BOM, by file name.
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

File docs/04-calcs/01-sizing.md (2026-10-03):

---
doc_id: PBX-CAL-001
title: PowerBox sizing calculations
project: PowerBox
doc_type: Calculation note
version: "0.4"
status: Draft
date: '2026-10-02'
author: Amish Chadha
license: CERN-OHL-S-2.0
revisions:
- version: "0.1"
  date: '2026-09-25'
  author: Amish Chadha
  change: First TRL 3 sizing note (energy, charging, converter efficiency, outputs, fuses, pre-charge, station mode, standby, wake, thermal, mass, cost) against SwapCell interface v0.3
- version: "0.2"
  date: '2026-10-01'
  author: Amish Chadha
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

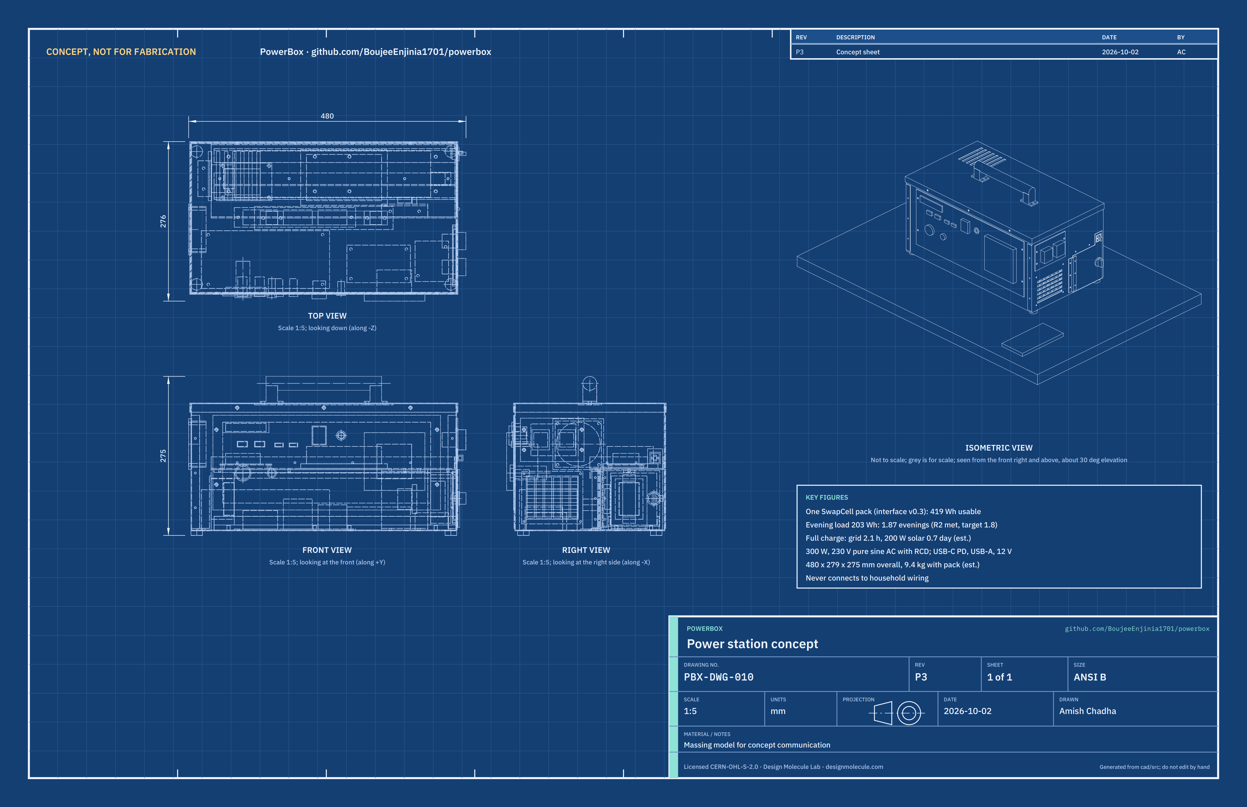
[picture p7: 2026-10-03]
media/concept-blueprint.png

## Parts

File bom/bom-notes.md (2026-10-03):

# BOM notes

Prices are indicative TRL 3 estimates with a supplier or supplier type for each line; named quotes are still needed before any purchase (TRL 4 work, on hold by Amish's instruction). Item numbers match the exploded view (`media/exploded.png`), the components table in `docs/02-concept.md` and the general arrangement PBX-DWG-001. Items 16 to 18 are in the BOM but not modelled.

**Value-engineering target: USD 450. Estimated cost of the constructable design: USD 483.00 for the PowerBox parts (USD 33 over the target).** The target is a hypothetical control target, not a limit (Amish, 2026-10-01). The concept design was USD 449.00; making it constructable (PBX-DDR-003) added USD 33 (PBX-CAL-001 v0.2 section 11). The total is printed by `docs/04-calcs/sizing.py`, which reads this file.

**The SwapCell pack is not included.** Amish decided on 2026-09-25 that a shared SwapCell pack is priced once, in the SwapCell BOM (about $414 in prototype parts), and excluded from each dependent kit budget. Line 4 is therefore listed at $0.00. For reference only, one PowerBox with its own pack is about $863 in parts.

Changes for the constructable design (PBX-DDR-003, 2026-10-01): lines 1, 2, 3, 5, 6, 15, 16 and 18 repriced for rivet nuts and windows in the body, the deeper lid skirt, the handle doubler, the shelf, brackets, runners and rail, the door hinge, cam latch and staple, the filter frame, the protection plate and the counted fixings (USD 33 in all). Making sketches PBX-DWG-101 to 113 are named in the notes column.

Change of 2026-10-02: line 11 now has the lit rocker main switch decided by Amish (about USD 1 more, USD 46 to USD 47); the switch hole in the output panel plate is 22 x 30 mm with a 25 x 33 mm bezel. The AC outlet in line 12 stays generic until the first partner's country is known (decided 2026-10-02: the national socket of that country, never a universal socket).

Changes from TRL 2:

- Line 10: the 48 V to 12 V buck is now 30 A (360 W), up from 20 A, because every DC output at its rating needs about 26.5 A (PBX-CAL-001 section 5). About $10 more.
- Line 5: adds the class D latch catch and the 10 kΩ ±1 % INTERLOCK coding resistor required by SwapCell interface v0.3 item W. About $2 more.
- Line 11: adds a recessed, normally closed wake button in the INTERLOCK loop. About $1 more.
- Line 16: fuse and breaker ratings from PBX-CAL-001 section 6, including a pre-charge relay and resistor for the inverter. About $1 more.
- Lines 9 and 12: 230 V 50 Hz with a 30 mA RCD (decided by Amish, 2026-09-25); the inverter output must be isolated so its neutral can be bonded.

The grid charger (line 17, $50) is the same class of certified 54.6 V, 5 A charger as the SwapCell dock charger. A household or charging point that already has a SwapCell dock can omit it, bringing the PowerBox parts to USD 433 (USD 399 for the concept design).

The largest cost drivers are the inverter ($70), the grid charger ($50), the output panel ($46) and protection and wiring ($38). The DC-only variant without the inverter and AC outlet saves about $92 and removes all mains voltage from the box.

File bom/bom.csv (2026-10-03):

item | qty | spec | supplier | unit_cost_usd | make_buy | notes
1 Enclosure body | 1 | Folded 1.2 mm 5052 aluminium tub, 460 x 260 x 220 mm, from one blank; corner tabs folded from the end walls onto the long walls, 3 blind rivets each; pack door opening, output and input panel windows, intake slots, 76 mm fan exhaust hole, 24 floor holes; 14 M4 rivet nuts (lid and panels) | Local sheet metal shop | 38.00 | make | Indicative price for one-off folding; about 1.22 kg after openings (PBX-CAL-001); aluminium decided by Amish 2026-09-25; making sketch PBX-DWG-101; repriced for the windows and rivet nuts (PBX-DDR-003)
2 Lid with exhaust slots | 1 | 1.2 mm 5052 aluminium tray, 464.4 x 264.4 mm, 16 mm skirt fitting over the outside of the walls with a 1 mm gap, exhaust slots, 6 screw holes and 4 handle bolt holes | Local sheet metal shop | 13.00 | make | Indicative price; about 0.47 kg; deeper skirt that locates on the walls (PBX-DDR-003); making sketch PBX-DWG-102
3 Carry handle | 1 | Folding steel or aluminium bar handle with two base plates, 200 mm span, rated 15 kg or more; 2 mm 5052 aluminium doubler plate 240 x 40 mm under the lid | Hardware store or case hardware supplier | 10.00 | buy | Indicative price; doubler added so the 1.2 mm lid carries the handle load (PBX-DDR-003); doubler sketch PBX-DWG-103
4 SwapCell pack (reference) | 1 | SwapCell interface v0.3: 13S2P 21700 lithium-ion, 46.8 V nominal, about 468 Wh, 340 x 90 x 80 mm body, 393 mm overall, 2.85 kg | SwapCell project | 0.00 | make | NOT INCLUDED: priced once in the SwapCell BOM (about $414 in parts) and excluded from this budget, decided by Amish 2026-09-25
5 Pack bay and blind-mate receptacle | 1 | 2 mm 5052 aluminium shelf with folded flanges; 3 mm aluminium catch bracket and receptacle bracket; four printed PETG floor runner lengths and two top guide rail lengths with M3 and M4 heat-set inserts (1 mm guide clearance per side); class D latch catch; SwapCell receptacle on a floating mount with a 10 kOhm +/-1 % INTERLOCK coding resistor | SwapCell project and self | 40.00 | make | Indicative price; receptacle is the SwapCell dock item 9 part; coding resistor per interface v0.3 item W; shelf, brackets, runners and rail made constructable (PBX-DDR-003); sketches PBX-DWG-104 to 108
6 Pack bay door | 1 | 1.2 mm 5052 aluminium door with hasp tab, stainless piano hinge on the front edge, thumb-turn cam latch (19 mm hole), flush padlock staple | Local sheet metal shop | 14.00 | make | Indicative price; hinge, cam latch and staple replace the magnetic catch (PBX-DDR-003); making sketch PBX-DWG-109
7 Multi-input charge controller | 1 | Buck-boost DC-DC, 12 to 60 V in, 200 W, CC-CV to 54.6 V with current limit set by the host; MPPT in host firmware; input TVS and reverse-polarity protection | Electronics distributor (module class) | 30.00 | buy | Indicative price; efficiency at 40 W and 12 V to be confirmed from a datasheet (R6 at risk)
8 Host controller | 1 | ESP32 with CAN transceiver, 120 ohm termination, relay drivers, current sensors on inputs and outputs; SwapCell station host (type 3) | Electronics distributor | 28.00 | buy | Indicative price; firmware is not part of TRL 3
9 300 W pure sine inverter | 1 | 48 V DC input (40 to 60 V), 300 W continuous, 600 W for 1 s, THD 3 % or less, 230 V 50 Hz, output isolated from the DC input so the neutral can be bonded, remote on/off, idle 10 W or less | Inverter supplier (certified 48 V unit) | 70.00 | buy | Indicative price; 230 V 50 Hz decided by Amish 2026-09-25; neutral bonding to be confirmed from the datasheet
10 DC-DC converter 48 V to 12 V | 1 | Non-isolated buck, 36 to 60 V in, 12 V 30 A (360 W) out, efficiency about 94 % | Electronics distributor (module class) | 30.00 | buy | Resized from 20 A to 30 A by PBX-CAL-001 (full DC output demand about 26.5 A); indicative price
11 Output panel | 1 | Panel with 1 x USB-C PD 100 W, 1 x USB-C PD 60 W, 2 x USB-A 12 W, 12 V car socket and 5.5 x 2.1 mm barrel, lit rocker main switch (snap-in, 22 x 30 mm panel hole, 25 x 33 mm bezel), recessed normally closed wake button in the INTERLOCK loop | Electronics distributor | 47.00 | buy | Indicative price; USB modules fed from the 12 V bus; lit rocker main switch decided 2026-10-02, about USD 1 more than a plain rocker (indicative distributor price for a snap-in illuminated rocker of the same class); 2 mm aluminium panel plate over a window in the front wall (PBX-DDR-003), sketch PBX-DWG-110
12 AC outlet with RCD | 1 | Single 230 V outlet with 30 mA RCD (RCBO or RCD socket), neutral bonded to case and earth pin | Electrical supplier | 22.00 | buy | Indicative price
13 State-of-charge display | 1 | 2.4 in TFT or e-paper, driven by the host | Electronics distributor | 10.00 | buy | Indicative price
14 Input panel | 1 | 2 x Anderson Powerpole PP45 (DC in and charger in, keyed by housing orientation), labelled, with dust caps | Electronics distributor | 14.00 | buy | Indicative price; 2 mm aluminium panel plate over a window in the end wall (PBX-DDR-003), sketch PBX-DWG-111
15 Exhaust fan and grille | 1 | 80 mm 12 V fan, about 16 L/s free air, thermostatic control from the host; fan grille; printed PETG intake filter frame holding a washable foam filter pad over the intake slots | Electronics distributor | 11.00 | buy | Indicative price; filter frame added (PBX-DDR-003); making sketch PBX-DWG-112
16 Protection and wiring | 1 | 30 A main fuse holder (60 V DC or higher, 1 kA breaking), 20 A DC breaker on the inverter feed, inverter relay with 47 ohm pre-charge resistor, all on a 2 mm aluminium protection plate; 6-way fuse block rated 58 V DC or more (15 A buck, 20 A DC in, 10 A charger, 10 A 12 V sockets, USB 10/7.5/5 A); 10 AWG, 14 AWG and 18 AWG wire, lugs, ferrules | Electronics distributor | 38.00 | make | Indicative price; ratings from PBX-CAL-001 section 6; protection plate added so the parts have a fixing (PBX-DDR-003); making sketch PBX-DWG-113
17 Grid charger | 1 | Certified 54.6 V 5 A CC-CV lithium-ion charger brick, universal AC input, Powerpole DC lead | Charger supplier (certified unit) | 50.00 | buy | Indicative price; same class as the SwapCell dock charger; omit where a SwapCell dock is on hand; not modelled
18 Hardware and consumables | 1 | Stainless fixings: 14 M4 rivet nuts, 14 M4 x 10 pan-head screws, 8 M4 x 12 button-head screws from below, 8 M4 button-head screws with nyloc nuts, 4 M5 x 16 bolts with nyloc nuts, 4 M3 x 10 screws, about 30 blind rivets 3.2 mm; 4 self-adhesive rubber feet 20 mm diameter, 8 mm tall; labels, heat-shrink | Hardware store | 18.00 | buy | Indicative price; fixings counted from the constructable model (PBX-DDR-003)

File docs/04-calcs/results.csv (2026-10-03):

id | value | target | status
R1 | 419 Wh usable (407 Wh with minimum cells) | 400 Wh or more | Met
R2 | 1.87 evenings (225 Wh per evening from the pack); 1.81 with minimum cells | 1.8 evenings (restated 2026-10-02) | Met
R3 | DC in 12 to 60 V 200 W MPPT; charger in; pack swap; SunSpoke panel on DC in | Four sources | Met (design review)
R4 | 2.1 h | 3 h or less | Met
R5 | 634 Wh per clear day; full in 0.70 day | Full in one clear day | Met
R6 | 90.5 % worst case (model); MPPT stability not analysed | 90 % or more from 40 to 200 W; stable MPPT | At risk
R7 | Outputs as specified; 12 V buck 30 A for 26.5 A demand; pack 11.5 A at 400 W | Output set in R7, 400 W total | Met (design review)
R8 | Off 3.2 %/month; ready 0.6 W; inverter auto-off | 5 %/month; 1.0 W; auto-off | Met
R9 | No AC inlet; DC bus 54.6 V; RCD needs bonded inverter neutral | No back-feed path; 60 V or less | Met (design review)
R10 | 9.4 kg; 480 x 279 x 275 mm | 10 kg; 500 x 300 x 280 mm | Met
R11 | USD 483 excluding the pack | Value-engineering target USD 450 | Over the target by USD 33
R12 | Door, runners and class D catch allow a one-hand swap; display reads PACK_STATUS and PACK_LIMITS | 30 s swap; status display | Not verifiable at TRL 3

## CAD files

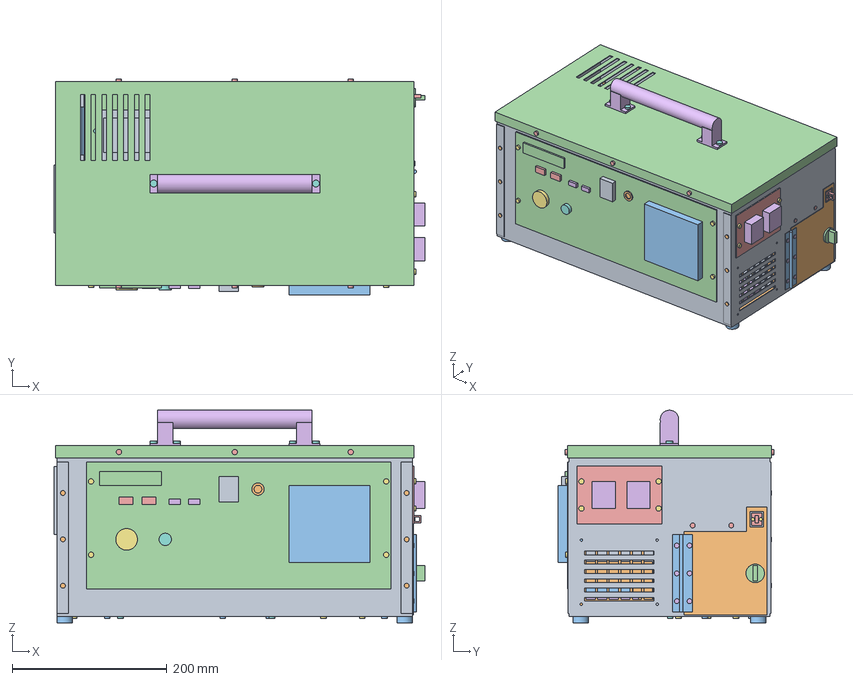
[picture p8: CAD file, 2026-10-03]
cad/step/powerbox-assembly.step
480.2 x 279.0 x 275.2 mm

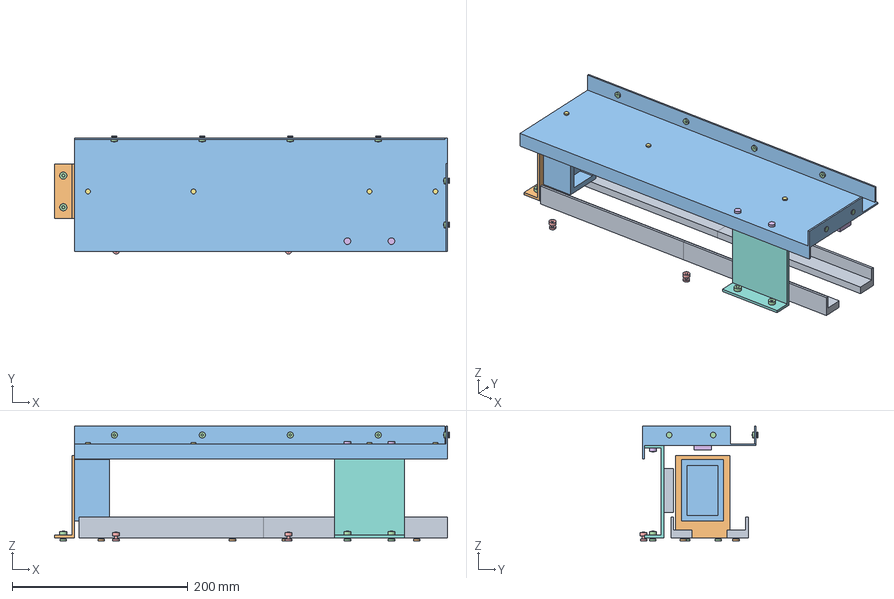
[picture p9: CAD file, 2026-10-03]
cad/step/powerbox-pack-bay.step
449.0 x 134.1 x 130.2 mm

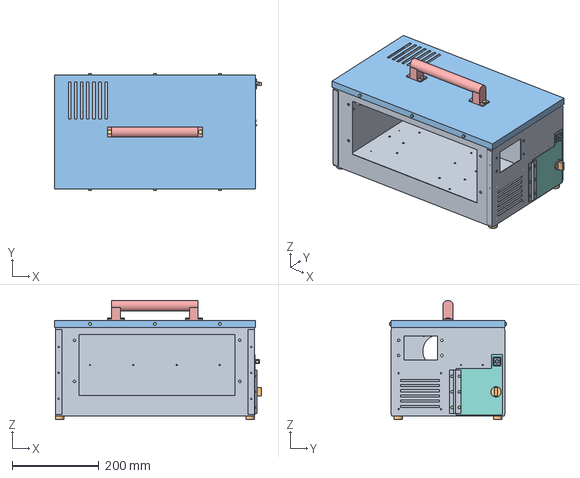
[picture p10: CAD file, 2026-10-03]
cad/step/powerbox-enclosure.step
478.4 x 270.0 x 275.2 mm

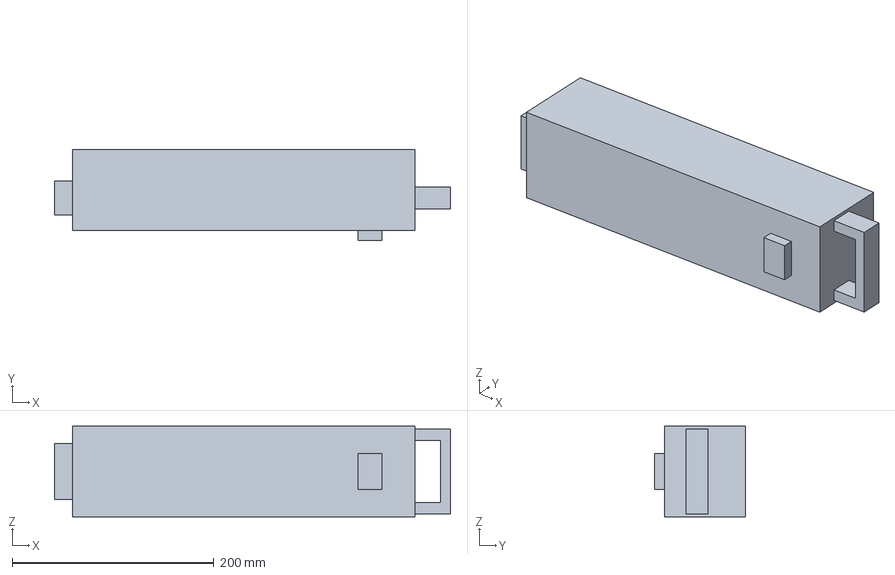
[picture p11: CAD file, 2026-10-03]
cad/step/swapcell-pack-reference.step
393.0 x 90.0 x 90.0 mm

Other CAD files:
cad/stl/powerbox-assembly.stl
cad/stl/powerbox-enclosure.stl
cad/stl/powerbox-pack-bay.stl
cad/stl/swapcell-pack-reference.stl

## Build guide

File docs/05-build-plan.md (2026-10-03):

---
doc_id: PBX-BLD-001
title: PowerBox prototype build plan
project: PowerBox
doc_type: Build plan
version: "0.3"
status: Draft
date: '2026-10-02'
author: Amish Chadha
license: CERN-OHL-S-2.0
revisions:
  - version: "0.1"
    date: '2026-10-01'
    author: Amish Chadha
    change: First build plan, with pictures by component and step; design made constructable (PBX-DDR-003)
  - version: "0.2"
    date: '2026-10-02'
    author: Amish Chadha
    change: "PBX-DDR-003 recorded as accepted; AC outlet stated as the national socket of the first partner's country with a bonded earth pin, never a universal socket (decided by Amish, 2026-10-02, PBX-DEC-001 item 10)"
  - version: "0.3"
    date: '2026-10-02'
    author: Amish Chadha
    change: "Lit rocker main switch and its 22 x 30 mm hole in the output panel plate; pictures redrawn from the updated model"
---

# PowerBox prototype build plan

**Plan, not yet built.** How to build the first proof-of-concept prototype, component by component. Building and testing to it is TRL 4 work. Decisions still to be made are kept in the design decisions register ([docs/06-design-decisions.md](06-design-decisions.md)), not here.

## 1. What you are building

Figure 1. Every component, pulled apart and numbered in build order

*Figure 1. Every component pulled apart and numbered in build order. The parts that sit on the case floor are drawn below the case.*

The prototype is one PowerBox: a folded aluminium case, 460 mm long, 260 mm deep and 220 mm tall, with a SwapCell battery pack sliding into a bay through a door in its right-hand end. Inside are bought power modules (an inverter, a 48 V to 12 V converter, a solar charge controller and a small controller board) and a shelf over the pack; the sockets are on a panel across the front, and the two charging inputs are on a small panel at the door end. Figure 1 shows the 23 components in the order you make or fit them. Thirteen are made: the case body, the lid, the handle doubler plate, the shelf, two folded brackets and the protection plate (all cut and folded from aluminium sheet), the door and the two panel plates (cut from sheet), and the floor runners, top guide rail and intake filter frame (3D printed). Everything else is bought and fitted. The work is cutting, drilling and folding aluminium sheet (a local sheet metal shop can fold the case, lid and shelf), setting rivet nuts and blind rivets, three short 3D prints, and wiring bought modules together. The parts cost about USD 482 from the bill of materials, without the pack, which comes from the SwapCell project.

> **Safety:** The prototype holds a 468 Wh lithium-ion SwapCell pack that can deliver about 500 A into a short, a 48 V bus, and an inverter that makes 230 V AC. Keep the pack out of the case and the main fuse out of its holder until section 6 says otherwise. The 230 V side is wired from certified parts and checked by a qualified electrician before it is ever switched on. PowerBox is standalone only: its AC outlet must never be connected to a wall socket or household wiring. Cut aluminium edges are sharp: deburr everything and wear gloves.

## 2. What changed to make it buildable

The concept showed what PowerBox does; many of its parts could not be made or fixed as drawn. Each change below keeps what PowerBox does, and all of them are recorded in decision record PBX-DDR-003, accepted by Amish on 2026-10-02.

*Table 1. Changes from the concept.*

| Component | The concept had | The buildable design has | Why |
| --- | --- | --- | --- |
| Lid | A tray standing on the 1.2 mm wall edges, with no fixing | A lid whose top rests on the walls and whose 16 mm skirt hangs outside them, held by six screws into rivet nuts (Figure 29) | It locates on all sides and comes off for service |
| Handle | A handle standing on the thin lid, with no fixing | Four bolts through the lid and a 2 mm doubler plate under it (Figure 27) | Spreads the carrying load |
| Floor runners | Runners 1 mm below the pack, nothing guiding its sides, too long to print | Four printed lengths with lips; the pack rests on them, the lips stand 1 mm off its sides (Figure 8) | The pack sits and is guided as intended |
| Shelf | A 4 mm slab resting on one bracket | A folded 2 mm shelf riveted to the back and end walls (Figure 17) | Fixed on three edges |
| Catch bracket and receptacle | A plate standing on its edge; the receptacle floating in the air | Two folded 3 mm brackets screwed to the floor (Figures 10 and 12) | Each part has a fixing |
| Pack bay door | A solid block with no hinge; no room for a magnetic catch | A sheet door on a piano hinge at its front edge, a cam latch and a padlock hasp (Figures 24 and 25) | The only edge with room for a hinge; the latch fits where a magnet cannot |
| Output and input panels | Blocks on solid walls; nowhere for the socket bodies | Windows in the walls covered by 2 mm panel plates; sockets in the plates (Figure 20) | Bought modules mount in a flat plate |
| Protection parts | Not placed anywhere | A protection plate on the floor between the inverter and the bay | Short path from the pack to the inverter |
| Fan end | Six slots, which the fan screws would have fallen on | One 76 mm hole behind the fan and grille | Twice the open area, and room for the screws |
| Corners, feet, filter | Not detailed | Riveted corner tabs (Figure 5), 8 mm rubber feet, a printed filter frame | Garage-buildable; screw heads clear the table |

The changes add about 0.8 kg (the prototype weighs about 9.4 kg with the pack) and leave the case within its size limit: 480 x 279 x 275 mm overall.

## 3. Making the components

Make and check each component before the assembly step that needs it. Sizes are in millimetres. "Front" is the side with the sockets; "left" and "right" are as seen standing in front of the case, so the fan is at the left end and the pack door at the right end. Workshop tolerance is 0.5 mm unless a step says otherwise; drawings do not carry tolerances before TRL 4.

### 3.1 Enclosure body

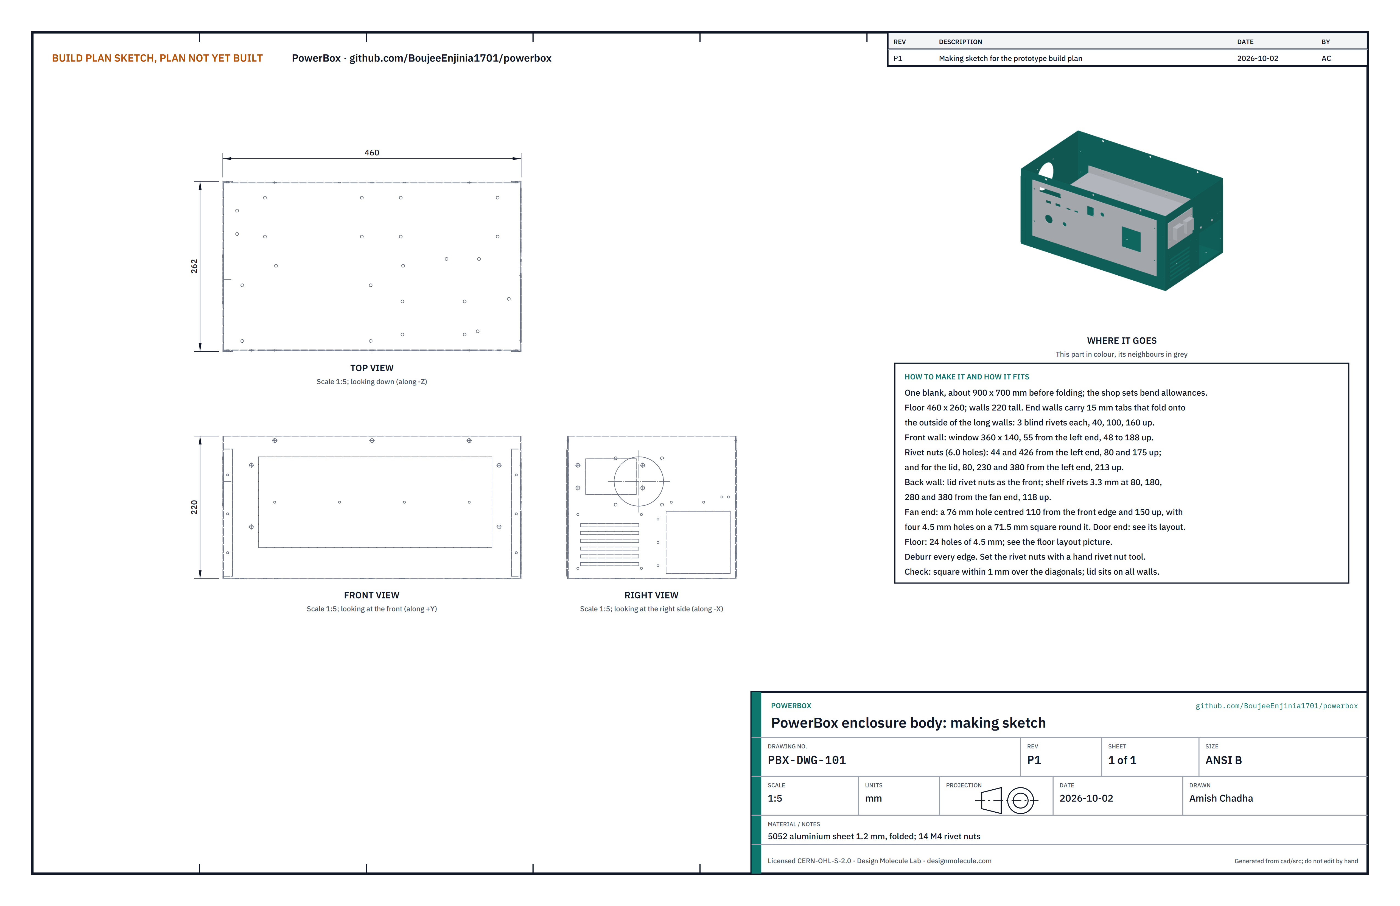
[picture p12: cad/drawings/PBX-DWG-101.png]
Figure 2. Making sketch of the enclosure body


*Figure 2. Enclosure body making sketch (PBX-DWG-101).*

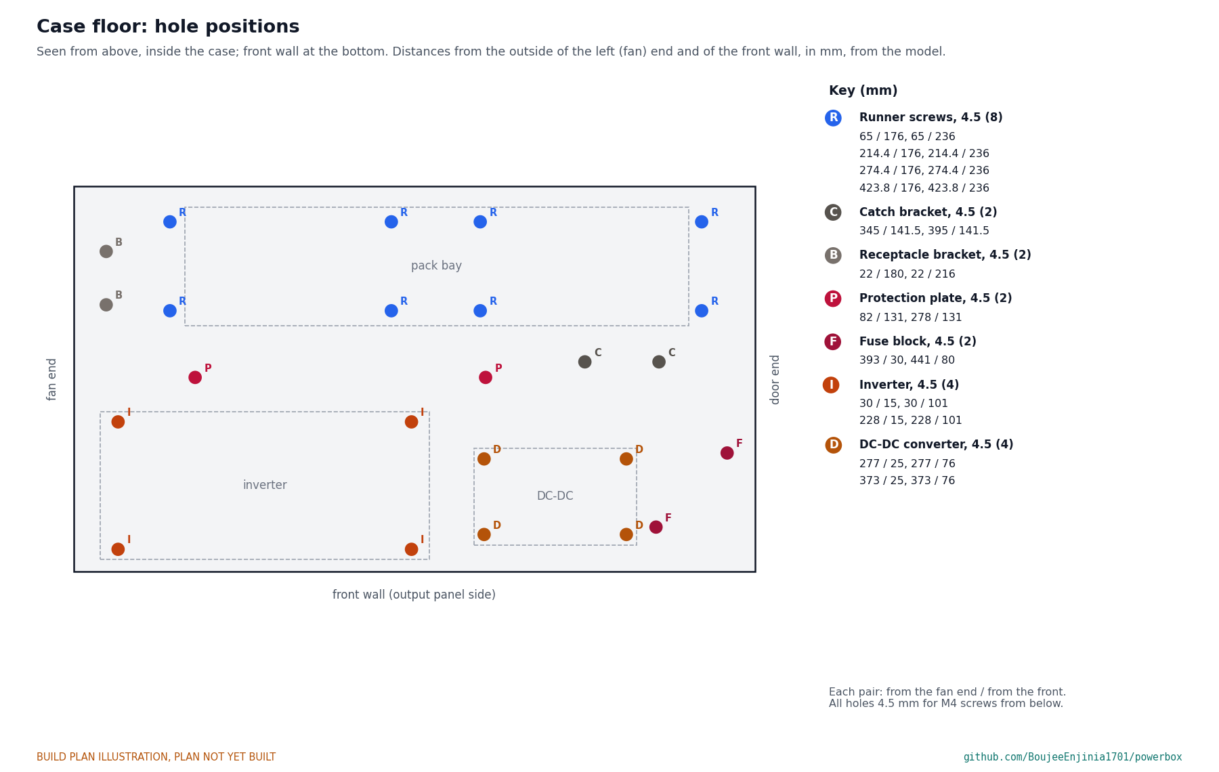
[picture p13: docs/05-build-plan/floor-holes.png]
Figure 3. Hole positions in the case floor


*Figure 3. The 24 holes in the floor, from the outside of the left end and of the front wall.*

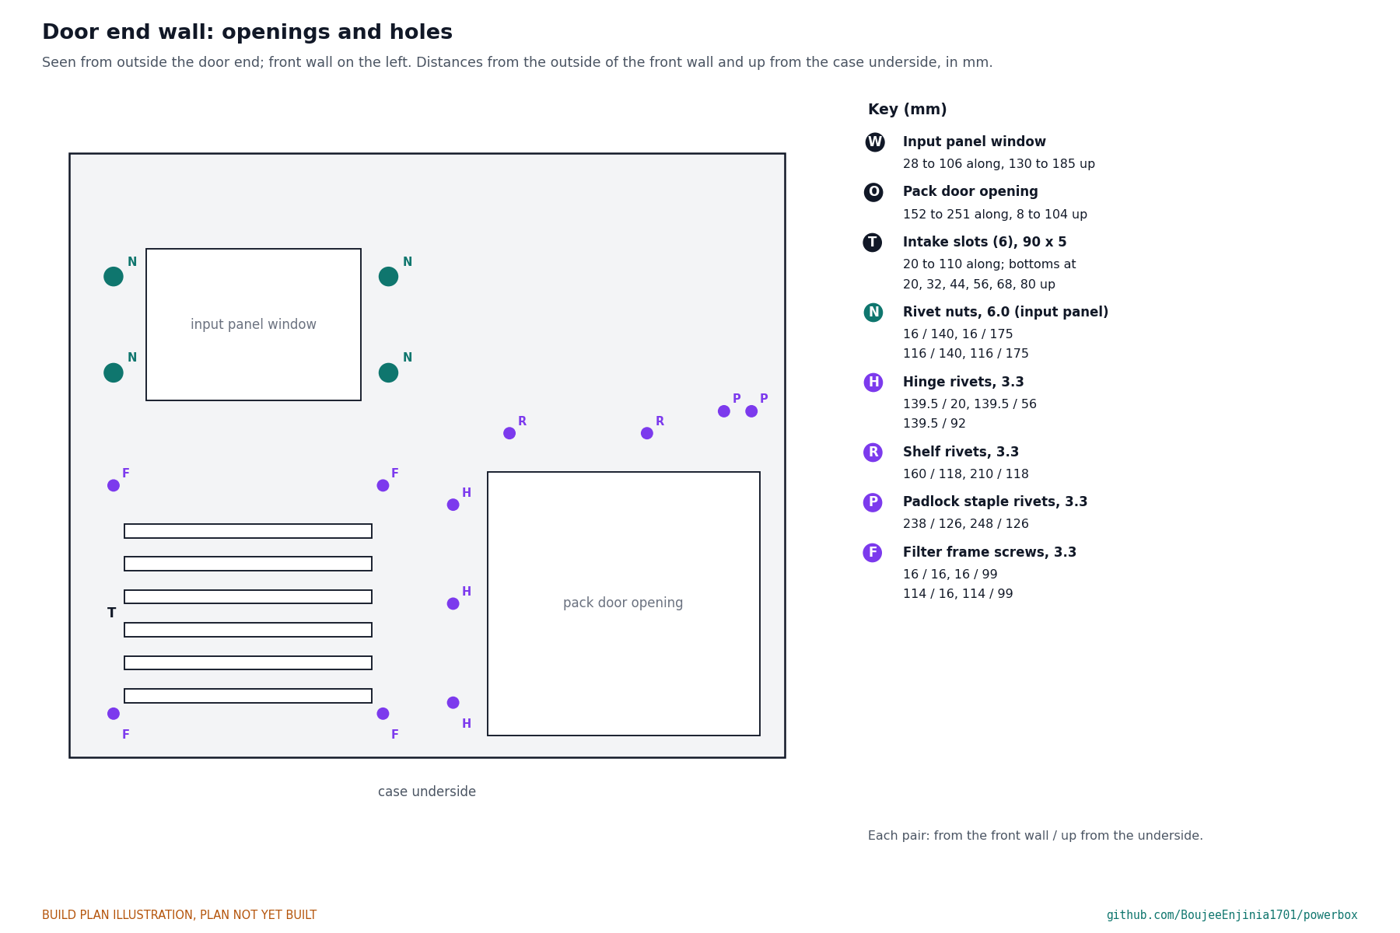
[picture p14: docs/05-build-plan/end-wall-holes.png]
Figure 4. Openings and holes in the door end wall


*Figure 4. The door end wall, seen from outside, with the front wall on the left.*

**What it is and what it is made from.** The open-topped case everything goes in. One blank of 5052 aluminium sheet 1.2 mm thick, about 900 x 700 mm, folded into a tub 460 long, 260 deep and 220 tall. This is a job for a sheet metal shop with a box-and-pan folder.

**How to make it.**

1. Give the shop the outside sizes and the openings below; the shop sets the bend allowances. The two end walls carry a 15 mm tab on each side edge, to be folded round the corner onto the outside of the long walls.
2. Front wall: a window 360 wide and 140 tall, from 55 to 415 from the left end and from 48 to 188 up from the underside.
3. Door end wall (Figure 4): the pack door opening, 99 wide and 96 tall; six intake slots 90 x 5; the input panel window, 78 x 55.
4. Fan end wall: a 76 mm hole centred 110 back from the front wall and 150 up, and four 4.5 mm holes on a 71.5 mm square round it for the fan screws.
5. Floor: the 24 holes of Figure 3, all 4.5 mm.
6. Rivet nut holes, 6.0 mm (check against the rivet nut maker's figure): in the front and back walls at 80, 230 and 380 from the left end, 213 up (for the lid); in the front wall at 44 and 426 from the left end, 80 and 175 up (for the output panel); in the door end as Figure 4 (for the input panel).
7. Rivet holes, 3.3 mm: in the back wall at 80, 180, 280 and 380 from the left end, 118 up (shelf); in the door end as Figure 4 (shelf, hinge, padlock staple and filter frame). Drill the shelf rivet holes through the shelf flanges at step 6 instead if you prefer.
8. Fold the walls up, then fold each end wall's tabs onto the outside of the long walls. Drill each tab and the wall behind it at 40, 100 and 160 up and set three 3.2 mm blind rivets.
9. Set the 14 M4 rivet nuts with a hand rivet nut tool, flanges outside.
10. Deburr every edge and hole.

**How it fits the parts next to it.**

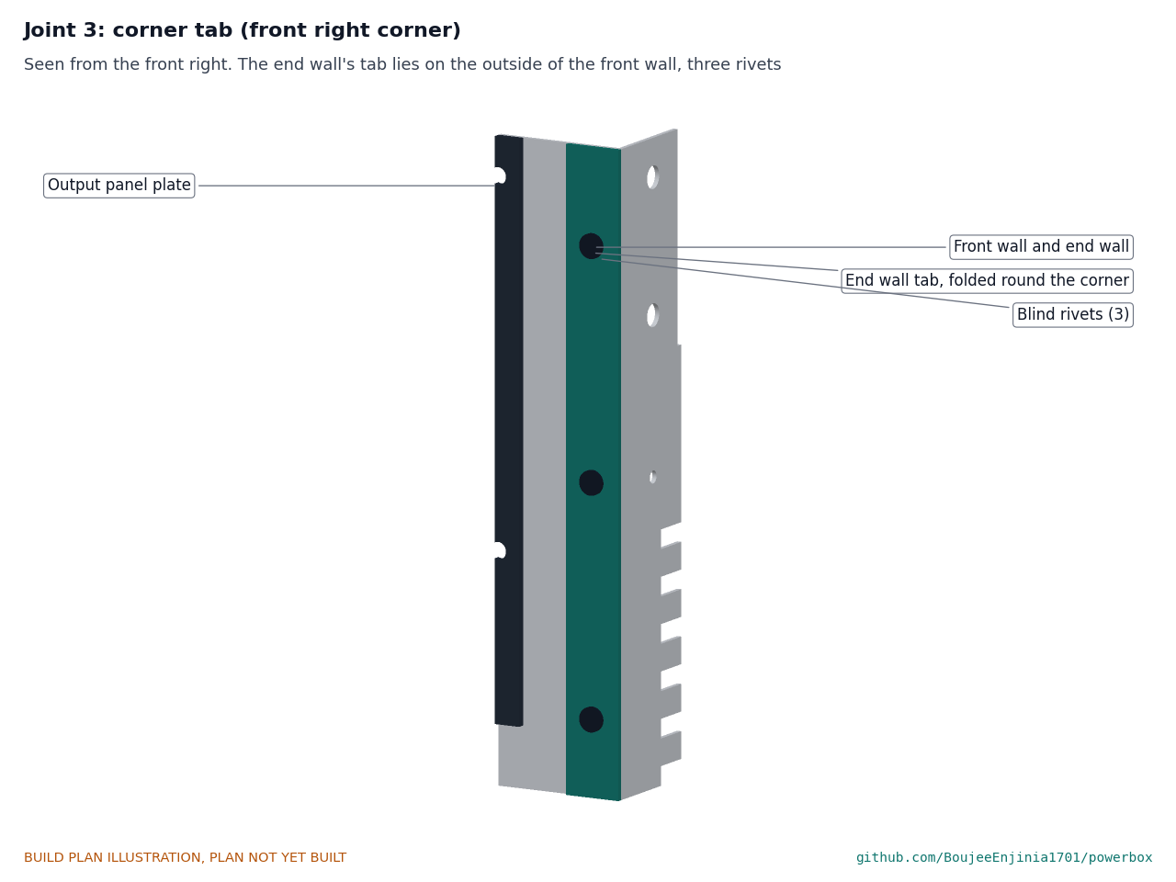
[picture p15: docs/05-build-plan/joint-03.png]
Figure 5. Joint 3: corner tab


*Figure 5. Each end wall's tab lies on the outside of the long wall and is held by three blind rivets.*

The lid rests on the top edges of the walls; the floor carries the runners, brackets and power modules on screws from below; the panels and door go on the outside of the walls.

**Check before moving on.** The diagonals of the top opening agree within 1 mm; the walls are square to the floor; every rivet nut turns an M4 screw freely.

### 3.2 Floor runners (make 4)

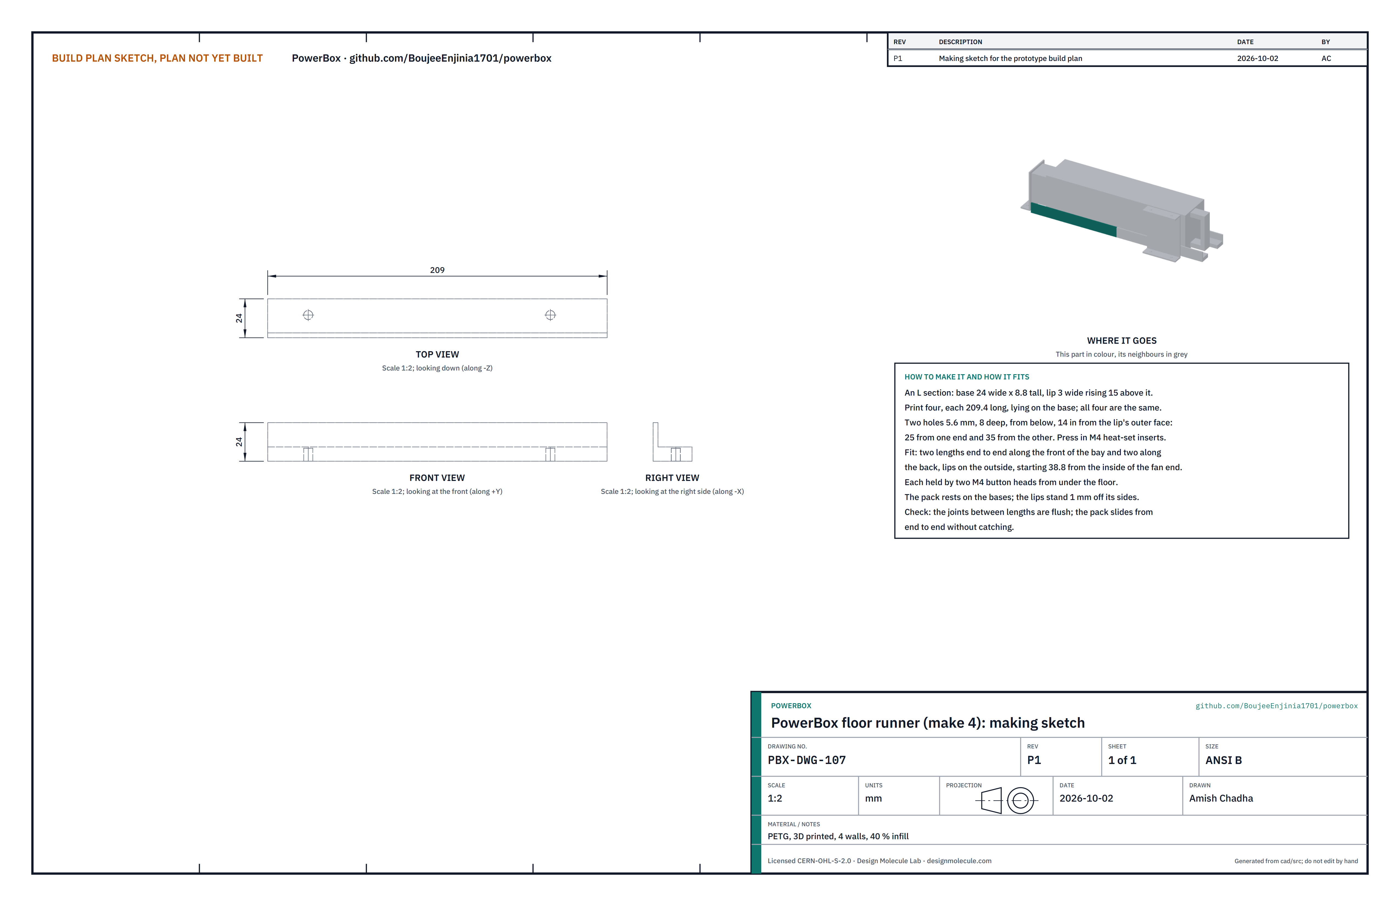
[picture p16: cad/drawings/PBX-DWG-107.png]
Figure 6. Making sketch of the floor runner


*Figure 6. Floor runner making sketch (PBX-DWG-107).*

**What it is and what it is made from.** The pack slides on these. Each is an L section, printed in PETG with four walls and 40 % infill: a base 24 wide and 8.8 tall, with a lip 3 wide rising 15 above it along one edge. Four lengths of 209.4, all the same.

**How to make it.**

1. Print each length lying on its base, lip up.
2. In the underside, two holes 5.6 mm and 8 deep, 14 in from the outer face of the lip, one 25 from one end and one 35 from the other.
3. Press an M4 heat-set insert into each hole with a soldering iron, flush with the underside.

**How it fits the parts next to it.**

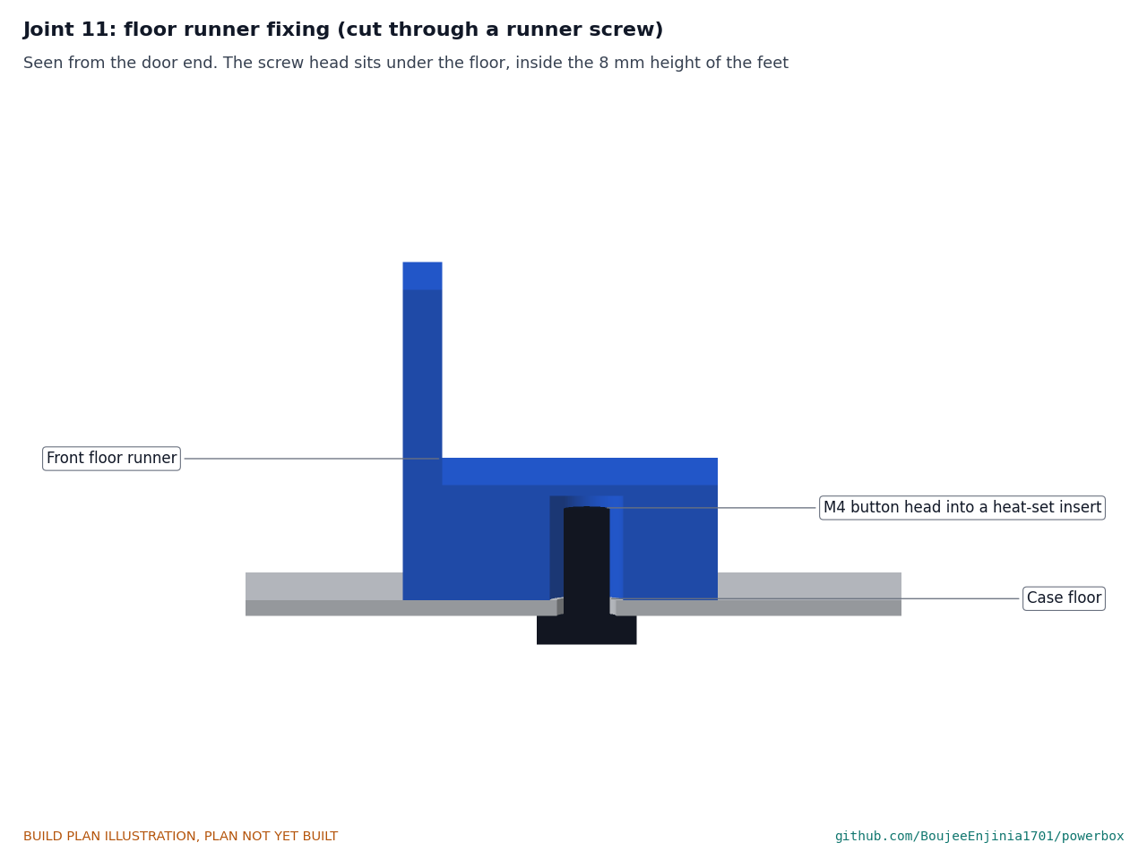
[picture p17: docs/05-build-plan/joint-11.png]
Figure 7. Joint 11: runner fixing


*Figure 7. An M4 button-head screw comes up through the floor into the insert; its head sits inside the height of the rubber feet.*

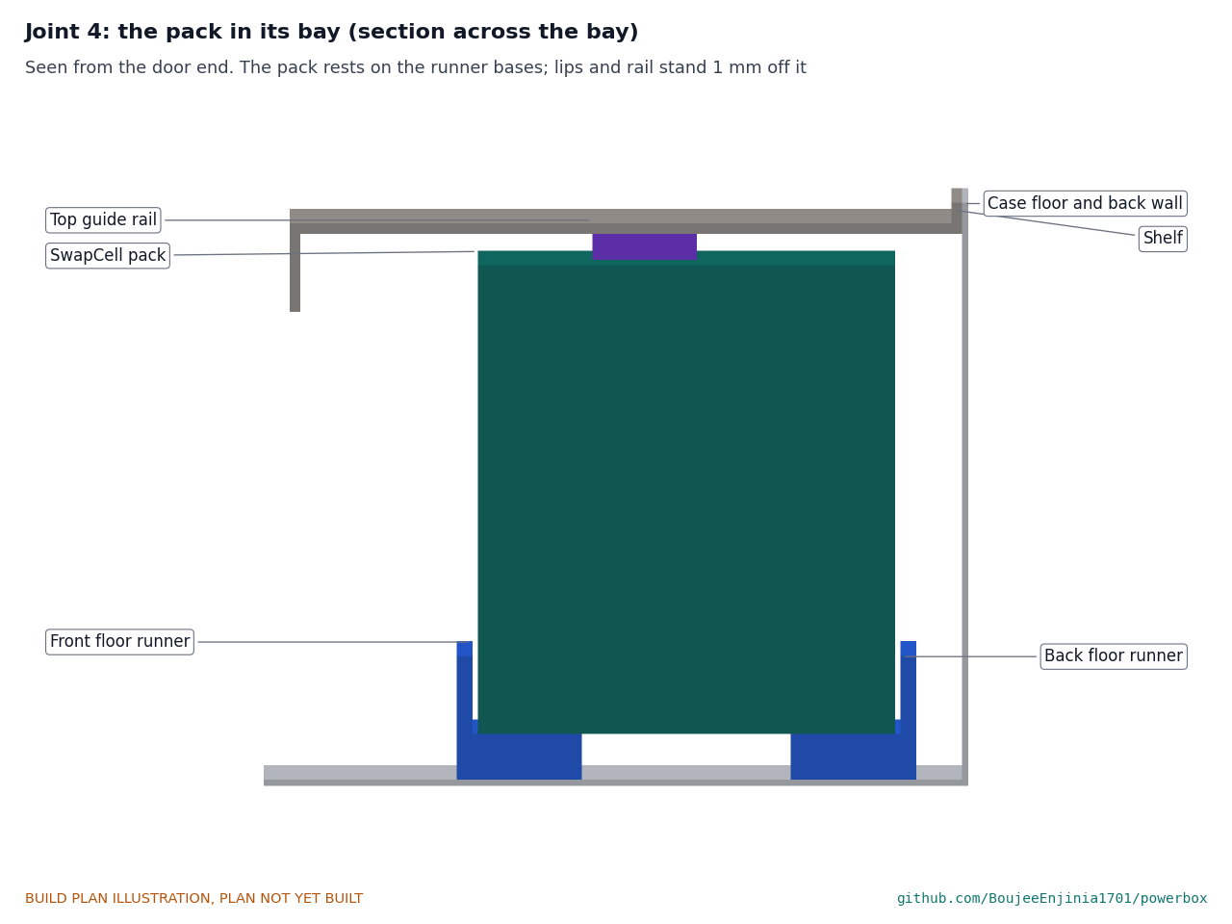
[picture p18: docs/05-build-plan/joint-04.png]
Figure 8. Joint 4: the pack in its bay


*Figure 8. Section across the bay: the pack rests on the runner bases; the lips and the top guide rail stand 1 mm off it.*

Two lengths go end to end along the front of the bay and two along the back, lips on the outside, starting 38.8 from the inside of the fan end and running to the door end wall. The pack's latch face is 1 mm inside the front lips and its lid face 1 mm inside the back lips.

**Check before moving on.** The joints between lengths are flush; a straight edge laid along the bases does not rock.

### 3.3 Catch bracket

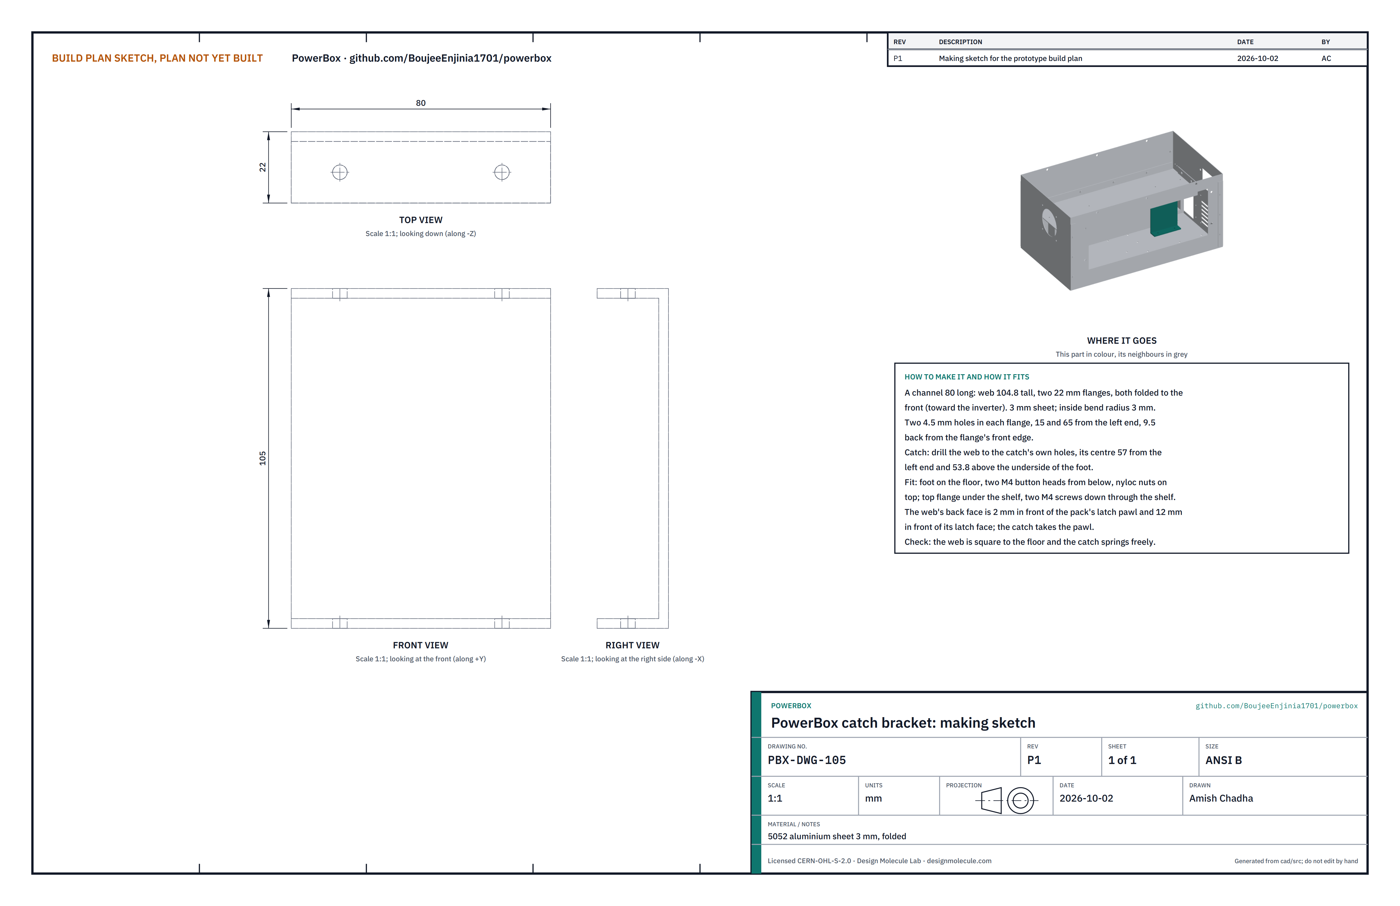
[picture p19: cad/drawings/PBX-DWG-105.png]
Figure 9. Making sketch of the catch bracket


*Figure 9. Catch bracket making sketch (PBX-DWG-105).*

**What it is and what it is made from.** The bracket that carries the latch catch, which holds the pack in place, and supports the front of the shelf. A channel 80 long folded from 5052 aluminium sheet 3 mm thick: a web 104.8 tall with a 22 mm flange at the bottom and at the top, both folded the same way.

**How to make it.**

1. Cut a blank 80 wide and about 145 long; fold both flanges 90° the same way, inside radius 3 mm, so the overall height is 104.8.
2. Drill two 4.5 mm holes in each flange, 15 and 65 from the left end, 9.5 back from the flange's front edge.
3. Drill the web to the latch catch's own holes, its centre 57 from the left end and 53.8 above the underside of the bottom flange.
4. Bolt the class D latch catch to the web with M4 screws and nyloc nuts.

**How it fits the parts next to it.**

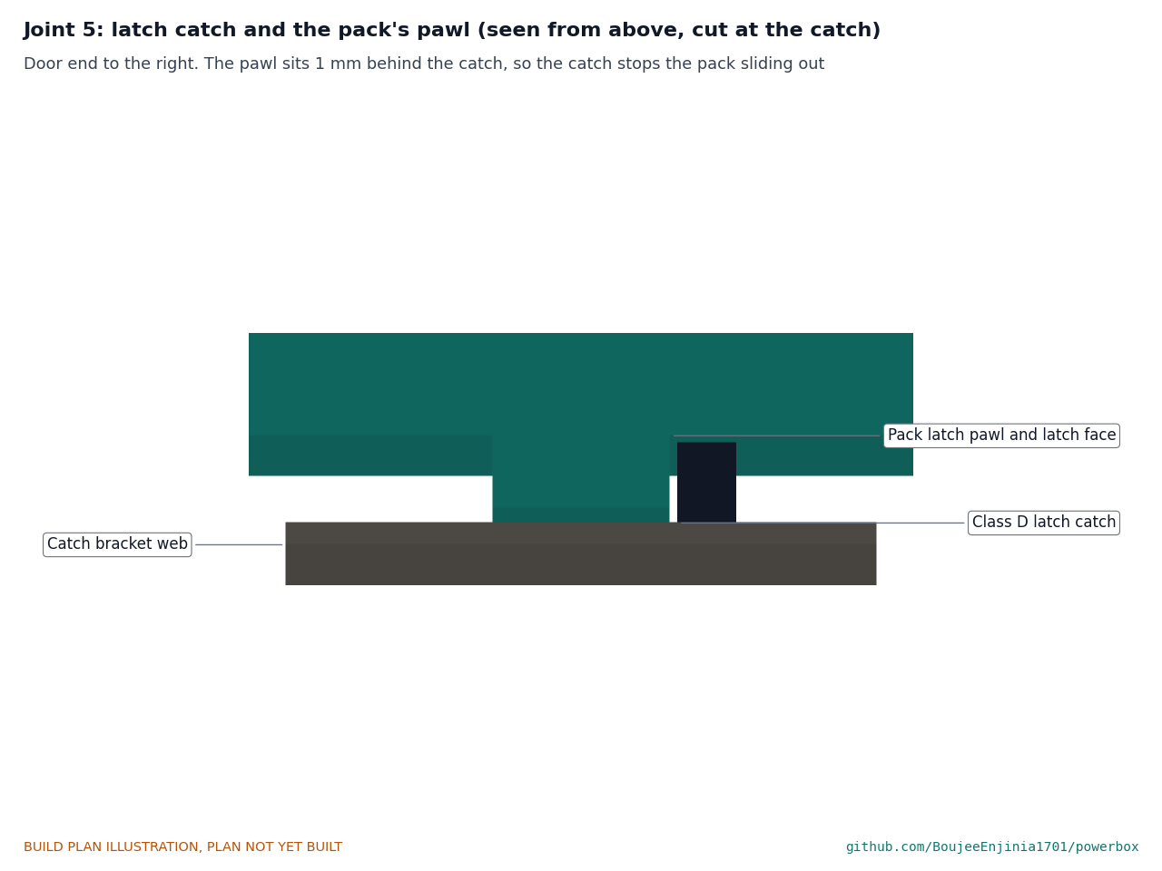
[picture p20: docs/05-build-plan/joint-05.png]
Figure 10. Joint 5: latch catch and pawl


*Figure 10. Seen from above: the pack's latch pawl sits 1 mm behind the catch, so the catch stops the pack sliding out.*

The flanges point to the front, toward the inverter. The bottom flange sits on the floor, held by two M4 button-head screws from below with nyloc nuts on top; the top flange sits under the shelf and two M4 screws come down through the shelf into it. The web's back face is 2 mm in front of the pack's latch pawl and 12 mm in front of its latch face.

**Check before moving on.** The web is square to the floor; the catch springs back freely when pushed.

### 3.4 Receptacle bracket

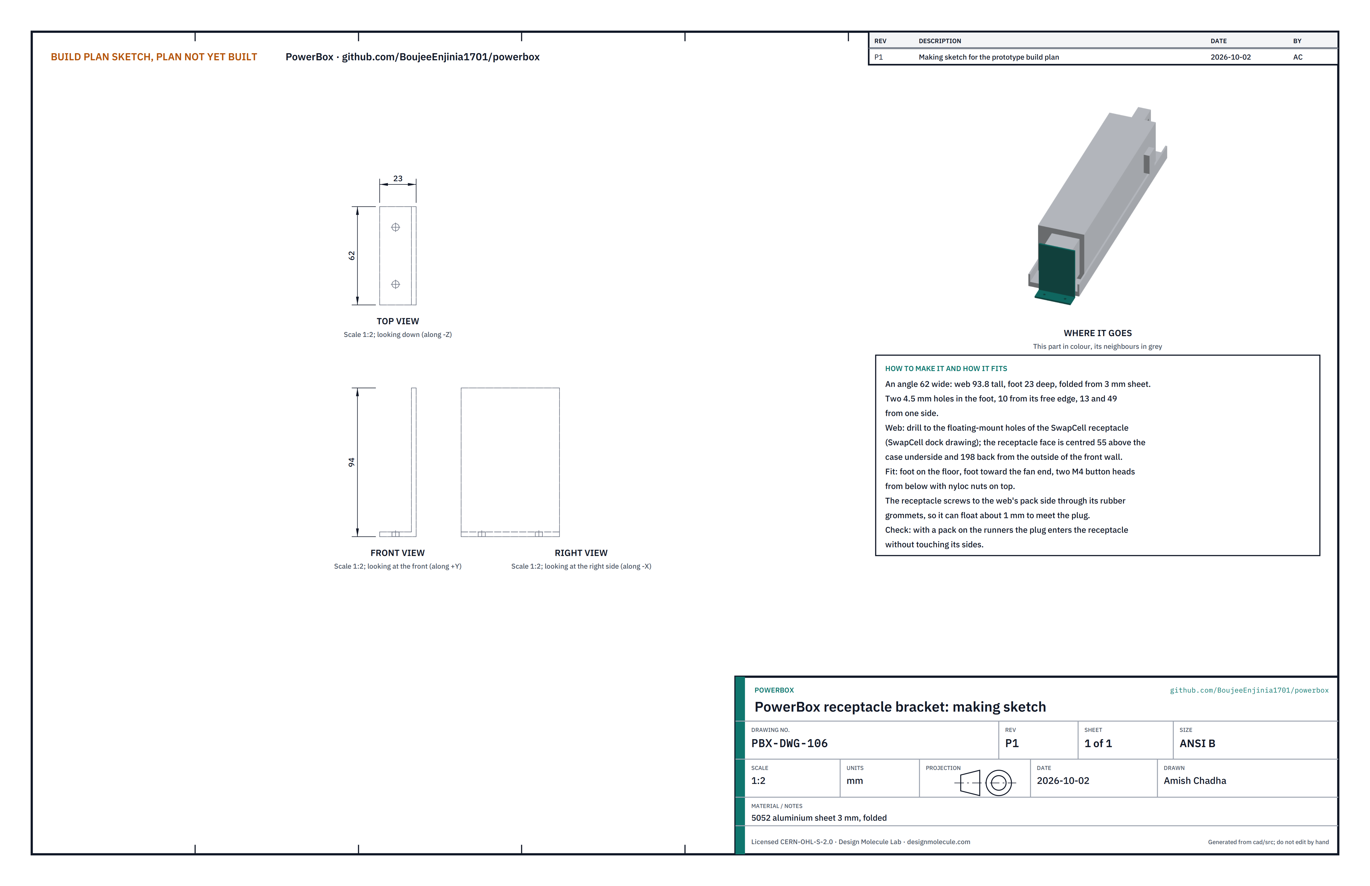
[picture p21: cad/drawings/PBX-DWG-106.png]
Figure 11. Making sketch of the receptacle bracket


*Figure 11. Receptacle bracket making sketch (PBX-DWG-106).*

**What it is and what it is made from.** The bracket that holds the SwapCell receptacle, which the pack plugs into, at the fan end of the bay. An angle 62 wide folded from 5052 aluminium sheet 3 mm thick: a web 93.8 tall and a foot 23 deep.

**How to make it.**

1. Cut a blank 62 wide and about 115 long and fold the foot 90°.
2. Drill two 4.5 mm holes in the foot, 10 from its free edge, 13 and 49 from one side.
3. Drill the web to the floating-mount holes of the SwapCell receptacle (from the SwapCell dock drawing), so the receptacle face is centred 55 above the case underside and 198 back from the outside of the front wall.

**How it fits the parts next to it.**

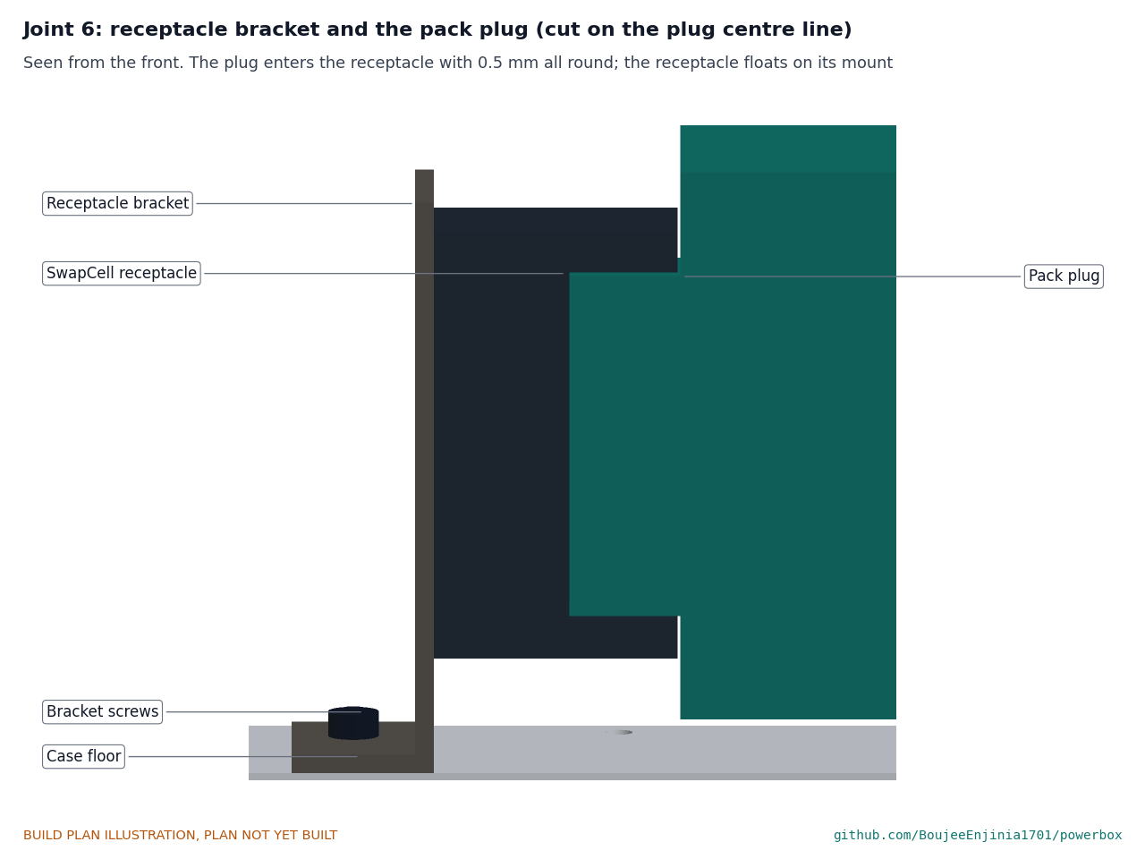
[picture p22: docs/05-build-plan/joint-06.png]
Figure 12. Joint 6: receptacle and plug


*Figure 12. The pack's plug enters the receptacle with 0.5 mm all round; the receptacle floats on its mount.*

The foot sits on the floor, pointing toward the fan end, on two M4 button-head screws from below with nyloc nuts on top. The receptacle screws to the pack side of the web through its rubber grommets, so it can float about 1 mm to meet the plug. The receptacle carries the 10 kilohm INTERLOCK coding resistor of SwapCell interface v0.3.

**Check before moving on.** With a pack on the runners, the plug enters the receptacle without touching its sides.

### 3.5 Protection plate

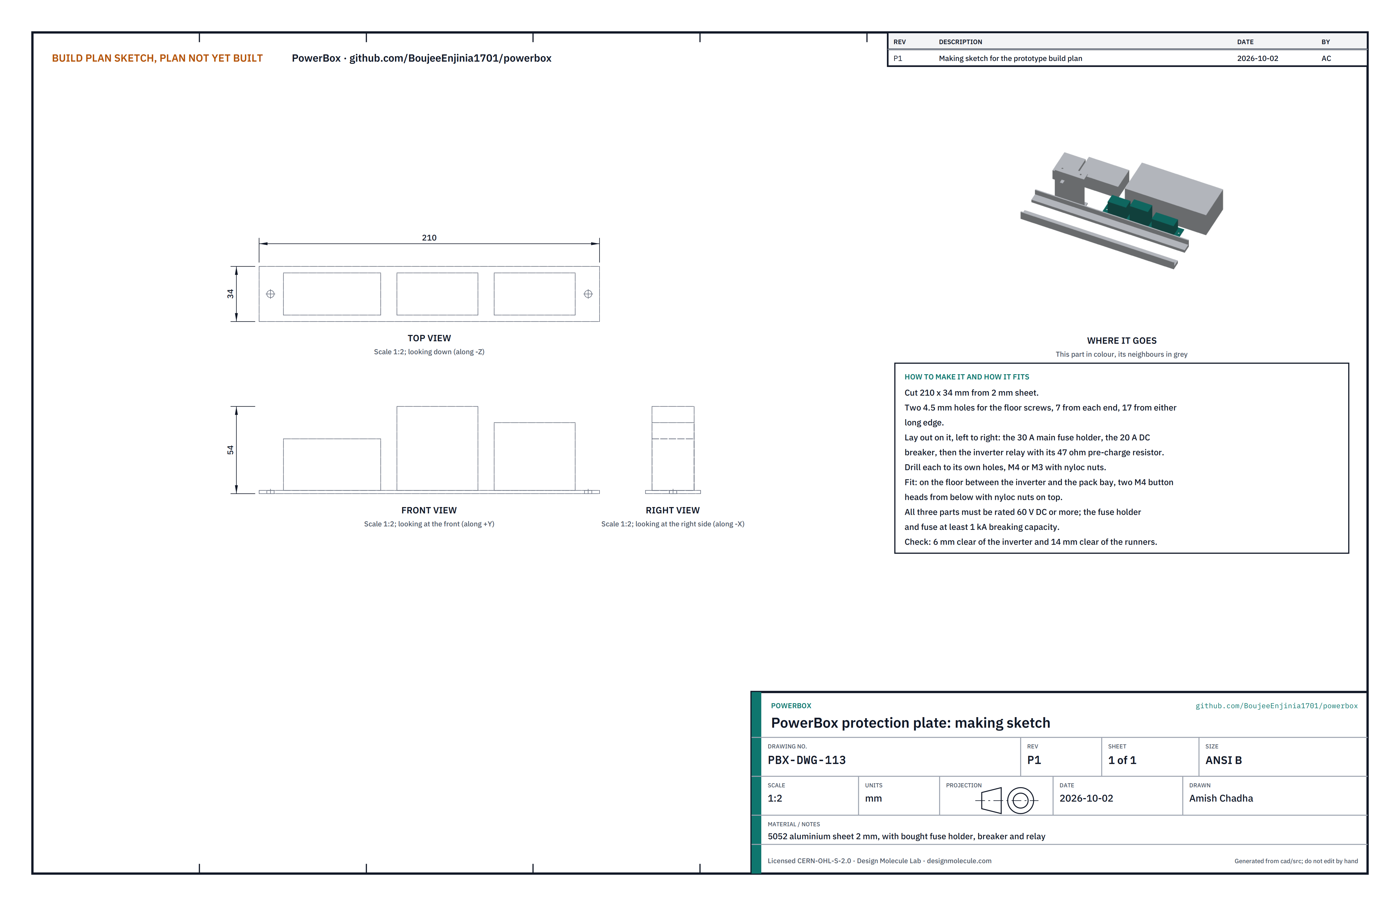
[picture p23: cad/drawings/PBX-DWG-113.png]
Figure 13. Making sketch of the protection plate


*Figure 13. Protection plate making sketch (PBX-DWG-113).*

**What it is and what it is made from.** A flat plate that carries the 30 A main fuse holder, the 20 A DC breaker for the inverter, and the inverter relay with its 47 ohm pre-charge resistor. 5052 aluminium sheet 2 mm, 210 x 34.

**How to make it.**

1. Cut the plate and deburr it. Drill two 4.5 mm holes, 7 from each end, 17 from either long edge.
2. Lay out the fuse holder, breaker and relay left to right; mark each part's holes through it, drill, and fit with M4 or M3 screws and nyloc nuts.

**How it fits the parts next to it.** The plate sits on the floor between the inverter and the pack bay, 6 clear of the inverter and 14 clear of the front runner, on two M4 button-head screws from below with nyloc nuts on top.

**Check before moving on.** Every part on the plate is rated 60 V DC or more, and the fuse holder and fuse at least 1 kA breaking capacity (read the labels and datasheets).

### 3.6 Intake filter frame

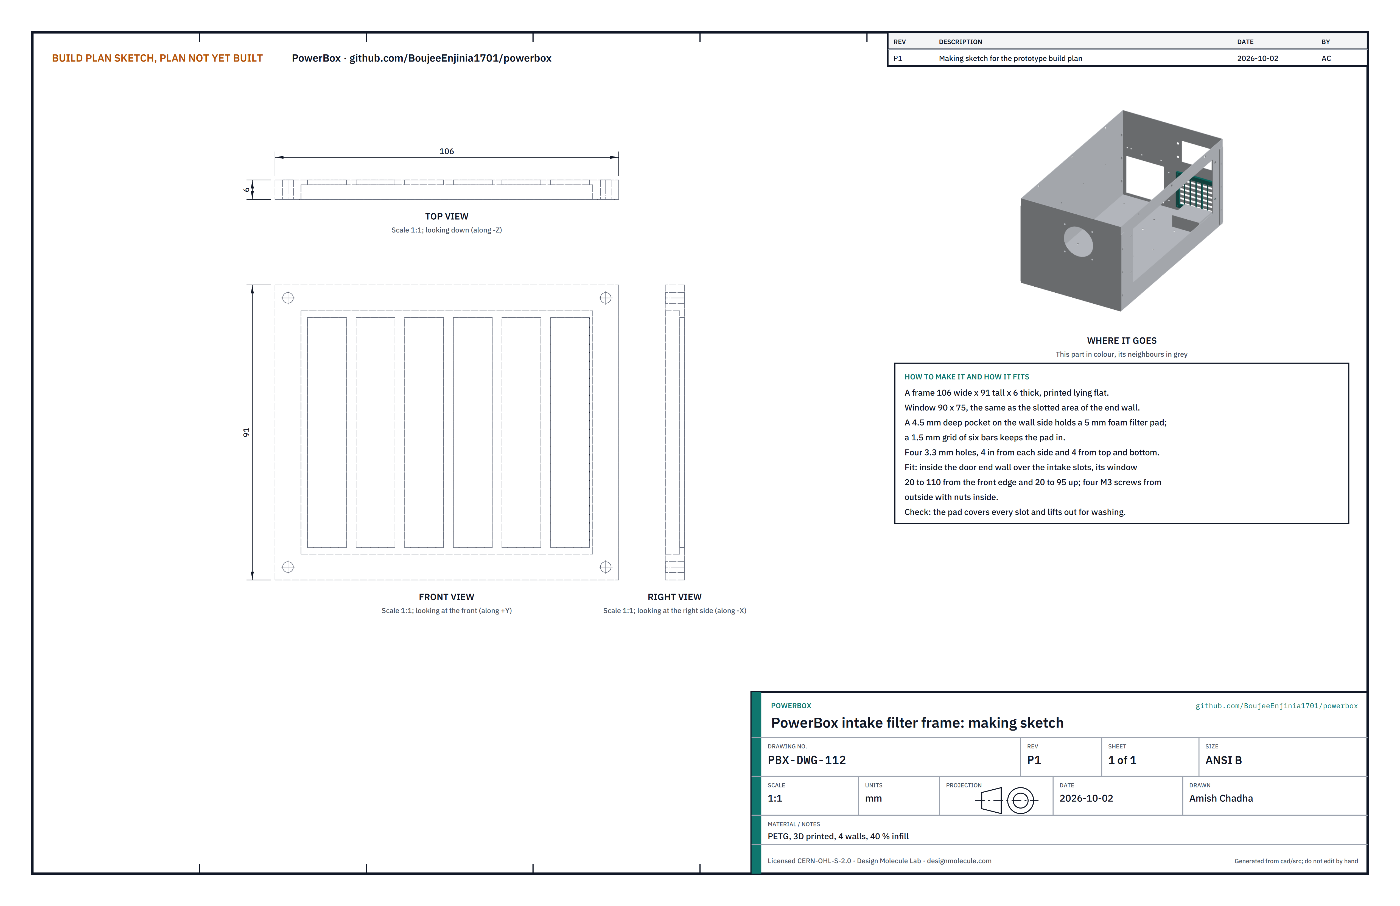
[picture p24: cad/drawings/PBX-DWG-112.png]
Figure 14. Making sketch of the intake filter frame


*Figure 14. Intake filter frame making sketch (PBX-DWG-112).*

**What it is and what it is made from.** A frame that holds a washable foam filter pad over the intake slots inside the door end. Printed PETG, 106 wide, 91 tall and 6 thick.

**How to make it.**

1. Print it lying flat, pocket side up: a window 90 x 75, a 4.5 mm deep pocket on the wall side for a 5 mm foam pad, and a 1.5 mm grid of six bars that keeps the pad in.
2. Drill or print four 3.3 mm holes, 4 in from each side and 4 from top and bottom.
3. Cut the foam pad to 90 x 75.

**How it fits the parts next to it.** The frame goes inside the door end wall with its window over the slots, 20 to 110 from the front wall and 20 to 95 up, on four M3 screws from outside with nuts inside.

**Check before moving on.** The pad covers every slot and lifts out for washing.

### 3.7 Top guide rail (make 2)

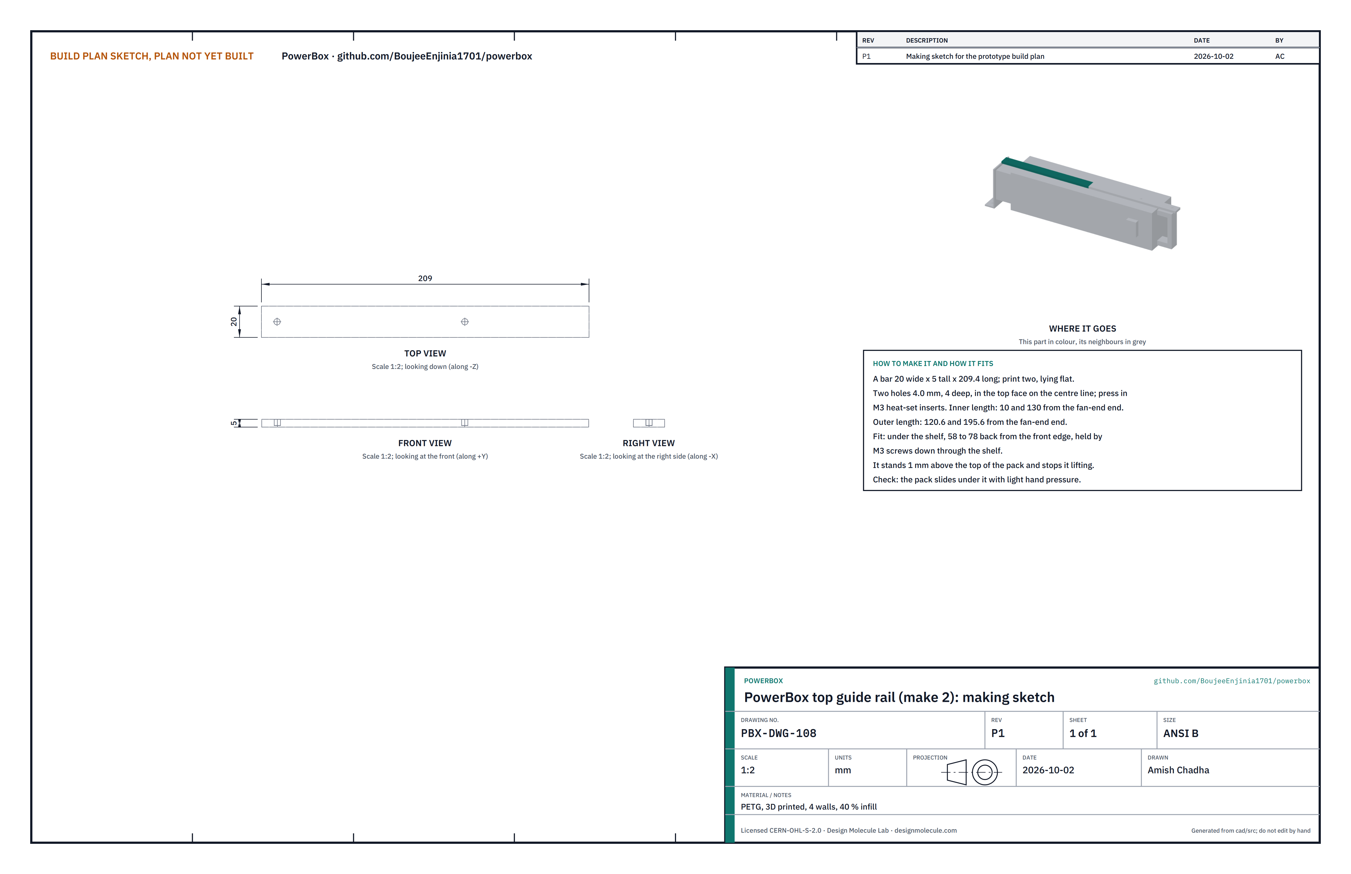
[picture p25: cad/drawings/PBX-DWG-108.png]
Figure 15. Making sketch of the top guide rail


*Figure 15. Top guide rail making sketch (PBX-DWG-108).*

**What it is and what it is made from.** A bar under the shelf that stops the pack lifting. Printed PETG, 20 wide, 5 tall, in two lengths of 209.4.

**How to make it.**

1. Print both lengths lying flat.
2. In the top face, on the centre line, two holes 4.0 mm and 4 deep in each length: in the inner length 10 and 130 from its fan-end end, in the outer length 120.6 and 195.6 from its fan-end end. Press in M3 heat-set inserts.

**How it fits the parts next to it.** Both lengths go end to end under the shelf, 58 to 78 back from its front edge, held by four M3 screws down through the shelf (step 5). The rail stands 1 mm above the top of the pack (Figure 8).

**Check before moving on.** The pack slides under the fitted rail with light hand pressure.

### 3.8 Shelf

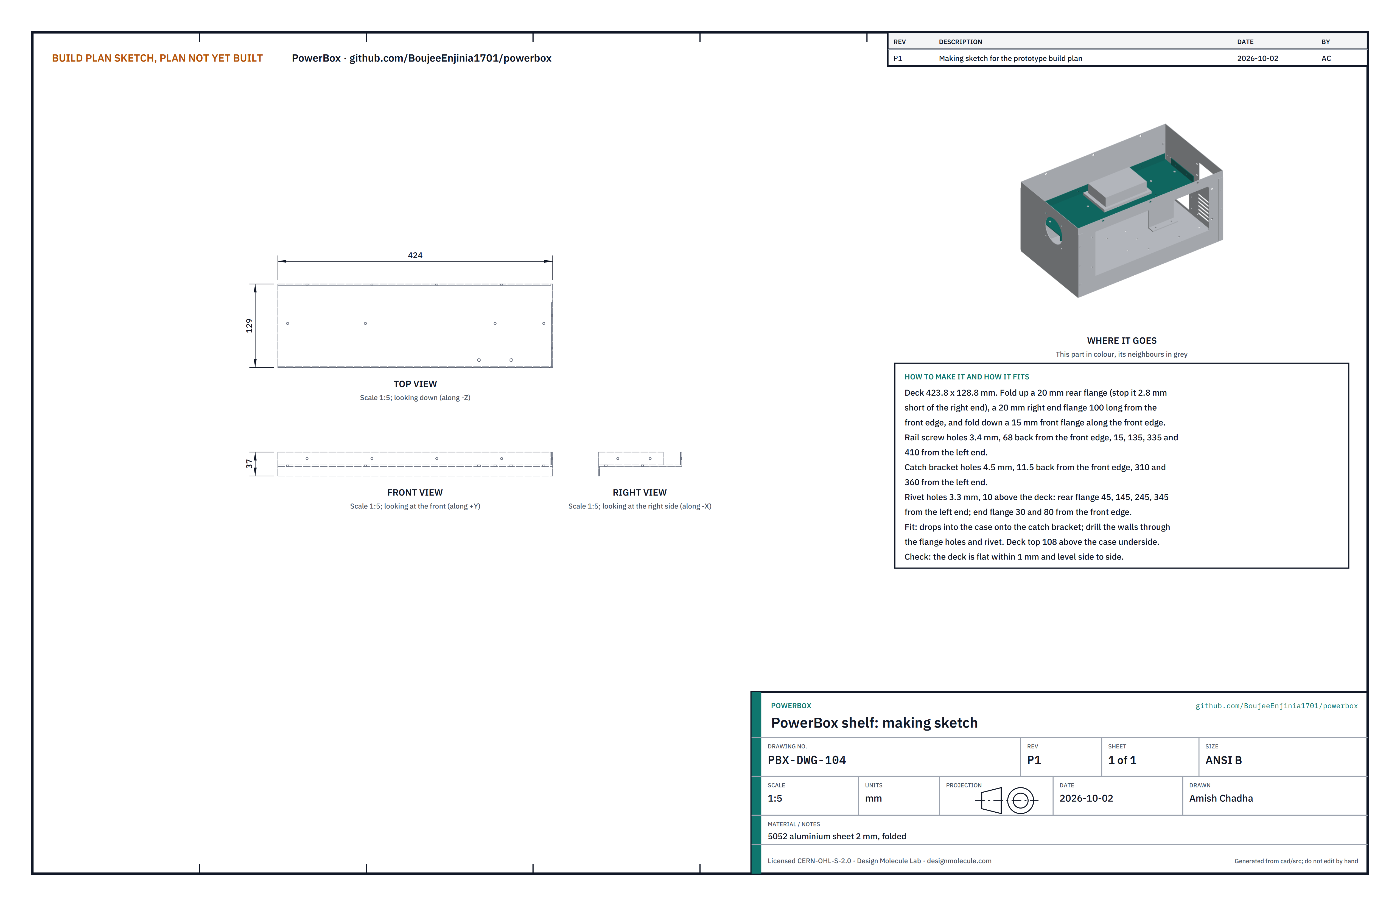
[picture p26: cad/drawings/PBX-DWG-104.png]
Figure 16. Making sketch of the shelf


*Figure 16. Shelf making sketch (PBX-DWG-104).*

**What it is and what it is made from.** The shelf over the pack that carries the charge controller and the controller board. 5052 aluminium sheet 2 mm, folded: a deck 423.8 x 128.8 with three flanges.

**How to make it.**

1. Cut the blank with a 20 mm rear flange (stopped 2.8 mm short of the right end for the corner), a 20 mm right end flange 100 long from the front edge, and a 15 mm front flange.
2. Fold the rear and end flanges up and the front flange down.
3. Drill the rail screw holes, 3.4 mm, 68 back from the front edge at 15, 135, 335 and 410 from the left end.
4. Drill the catch bracket holes, 4.5 mm, 11.5 back from the front edge at 310 and 360 from the left end.
5. Drill the rivet holes, 3.3 mm, 10 above the deck: in the rear flange at 45, 145, 245 and 345 from the left end; in the end flange 30 and 80 from the front edge.
6. Screw the top guide rail on (step 5).

**How it fits the parts next to it.**

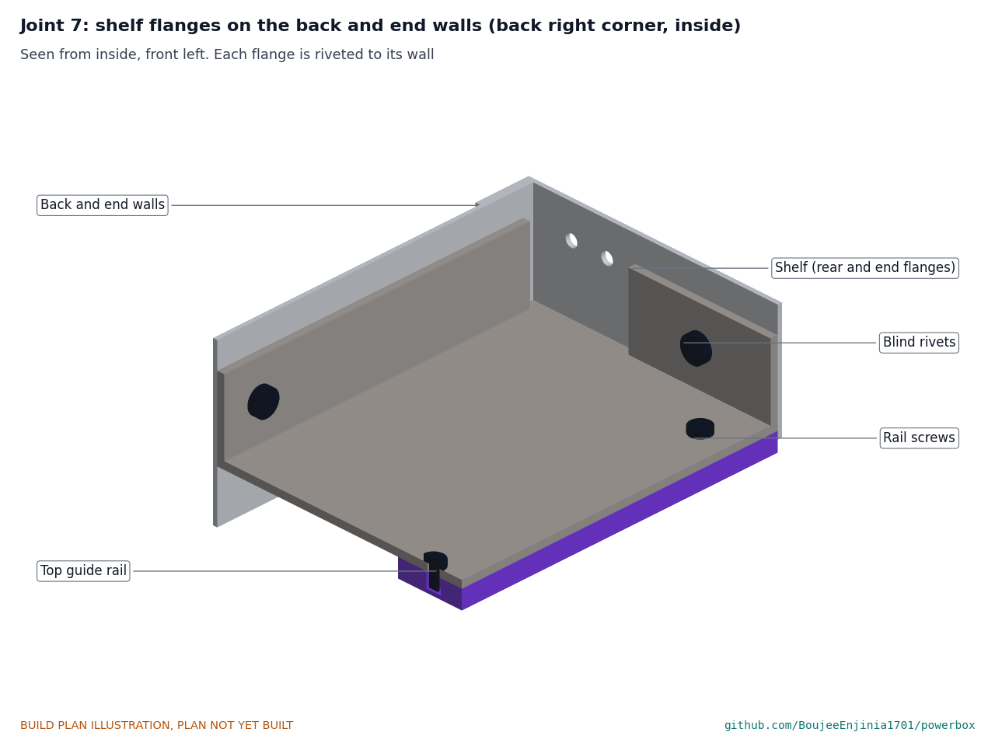
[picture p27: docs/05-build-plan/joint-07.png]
Figure 17. Joint 7: shelf flanges on the walls


*Figure 17. The rear and end flanges are riveted to the back and door end walls; the rail is screwed under the deck.*

The shelf drops into the case onto the catch bracket's top flange, its deck top 108 above the case underside, its left end 33.8 from the inside of the fan end. Its rear flange lies on the back wall and its end flange on the door end wall, above the door opening; six 3.2 mm blind rivets hold them, and two M4 screws hold the front to the catch bracket.

**Check before moving on.** The deck is flat within 1 mm and level side to side.

### 3.9 Output panel plate and its modules

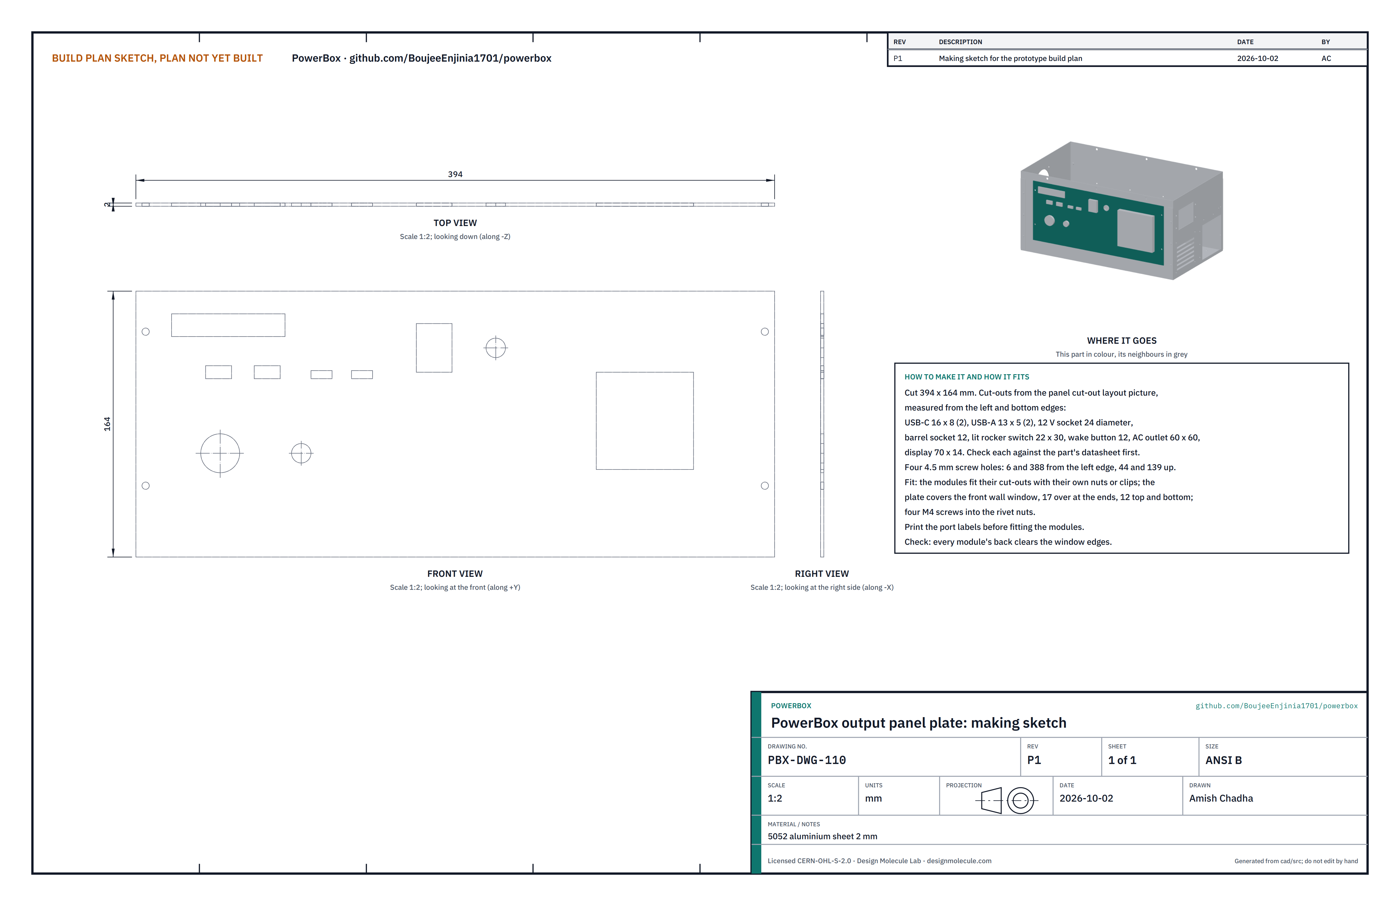
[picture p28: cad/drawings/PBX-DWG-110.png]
Figure 18. Making sketch of the output panel plate


*Figure 18. Output panel plate making sketch (PBX-DWG-110).*

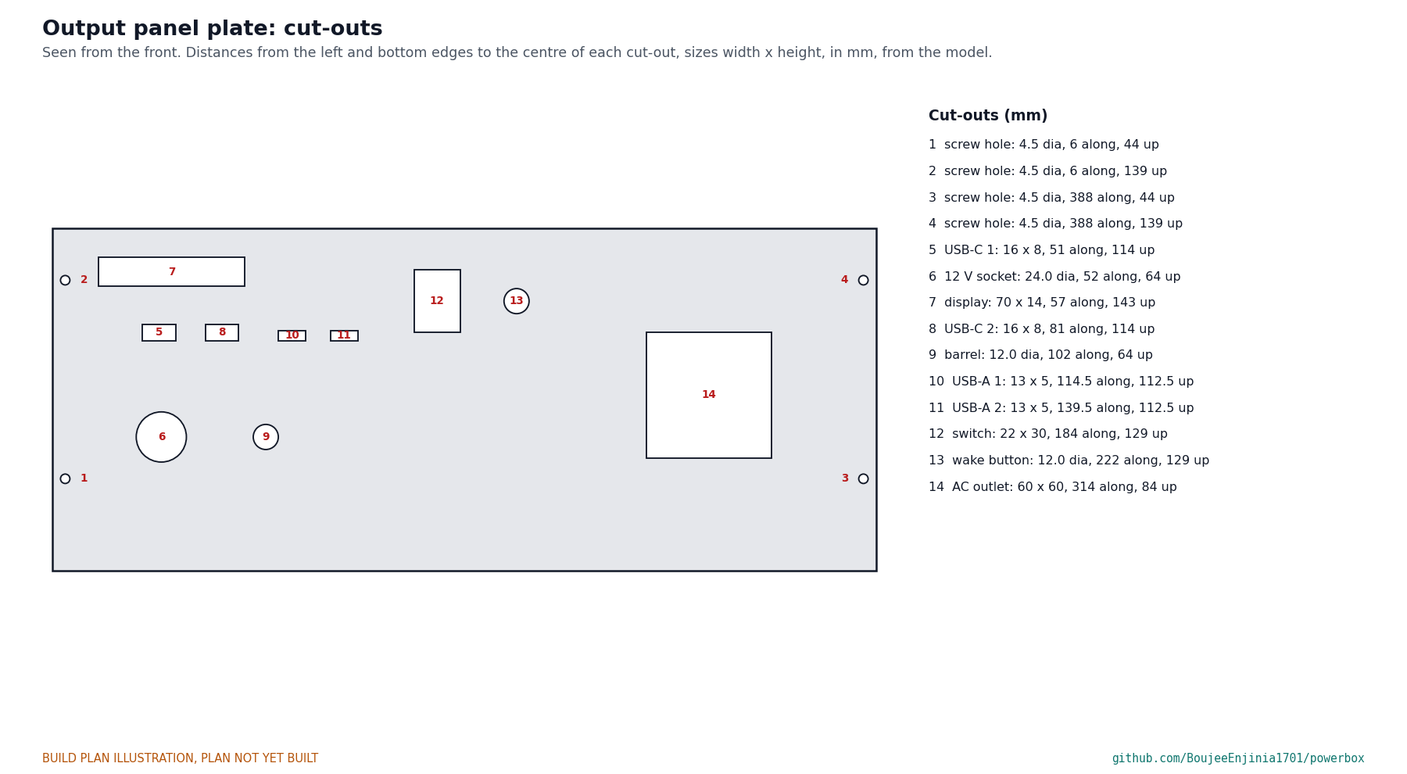
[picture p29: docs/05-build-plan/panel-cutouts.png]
Figure 19. Cut-outs in the output panel plate


*Figure 19. Every cut-out in the output panel plate, from the left and bottom edges.*

**What it is and what it is made from.** The front panel that carries the two USB-C and two USB-A ports, the 12 V car socket and barrel socket, the lit rocker main switch (a 22 x 30 mm hole), the recessed wake button, the AC outlet with its residual current device (RCD) and the display. 5052 aluminium sheet 2 mm, 394 x 164.

**How to make it.**

1. Cut the plate and mark the cut-outs of Figure 19. Before cutting, check each size against the datasheet of the module you bought.
2. Cut the rectangular openings by chain drilling and filing, the round ones with a step drill or hole saw. Drill the four 4.5 mm screw holes, 6 and 388 from the left edge, 44 and 139 up.
3. Deburr, then print or fix the port labels.
4. Fit the modules from the front, each with its own nut or clip (step 8).

**How it fits the parts next to it.**

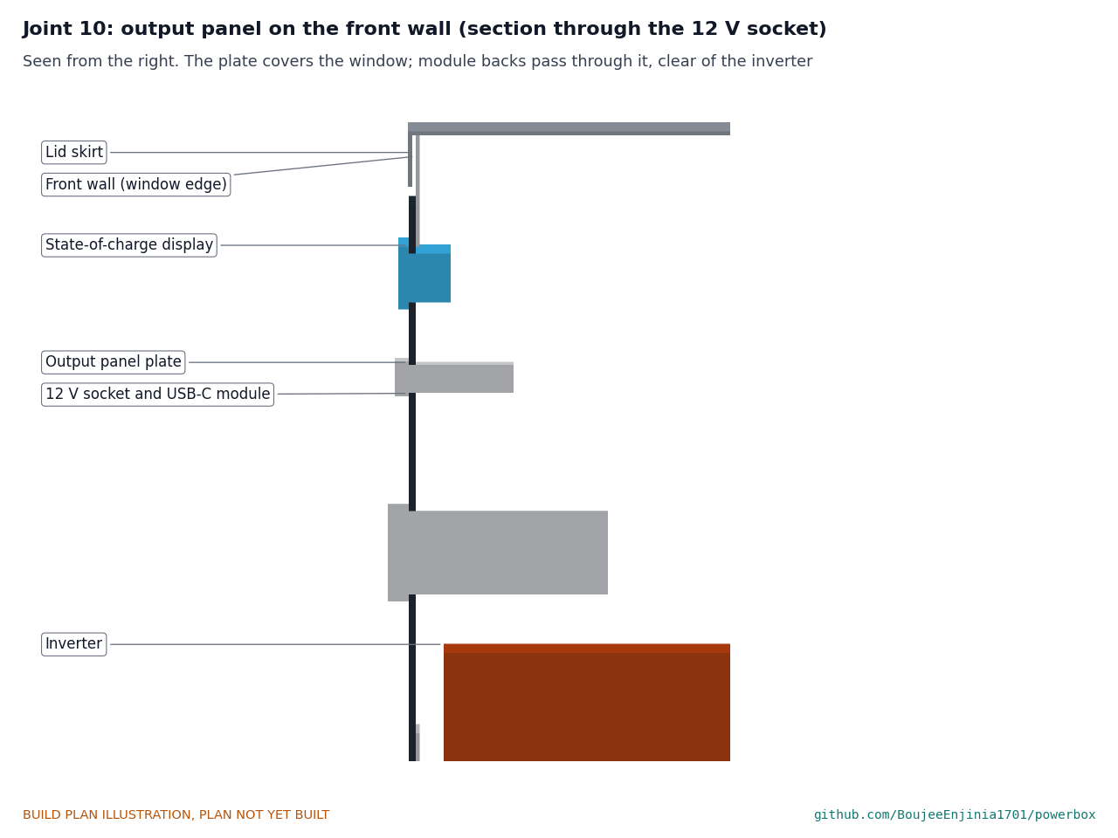
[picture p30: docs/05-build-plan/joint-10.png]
Figure 20. Joint 10: output panel on the front wall


*Figure 20. Section through the 12 V socket: the plate covers the window and the module bodies pass through it, clear of the inverter.*

The plate covers the front wall window, overlapping it 17 at each end and 12 at top and bottom, on four M4 screws into the rivet nuts. The 12 V socket body ends 17 above the inverter.

**Check before moving on.** Every module's body clears the edges of the window.

### 3.10 Input panel plate

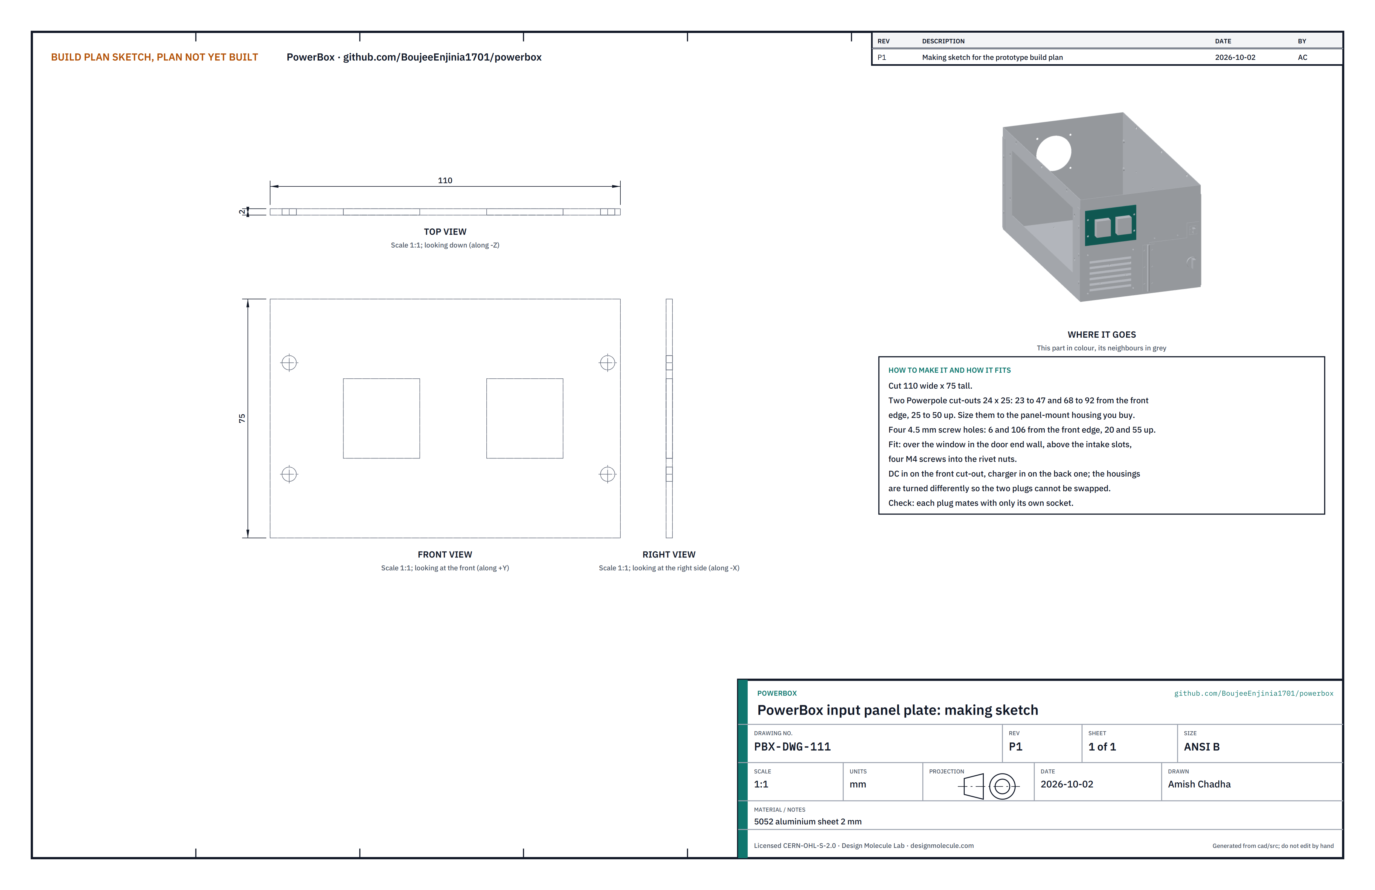
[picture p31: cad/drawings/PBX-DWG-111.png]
Figure 21. Making sketch of the input panel plate


*Figure 21. Input panel plate making sketch (PBX-DWG-111).*

**What it is and what it is made from.** The small panel at the door end that carries the two Anderson Powerpole inputs: DC in (solar panel or another 12 to 60 V source) and charger in (the 54.6 V grid charger brick). 5052 aluminium sheet 2 mm, 110 wide and 75 tall.

**How to make it.**

1. Cut the plate. Cut two openings 24 x 25 for the panel-mount Powerpole housings, 23 to 47 and 68 to 92 from the front edge, 25 to 50 up; size them to the housing you buy.
2. Drill four 4.5 mm screw holes, 6 and 106 from the front edge, 20 and 55 up.
3. Fit the housings: DC in at the front, charger in at the back, turned differently so the two plugs cannot be swapped. Label them.

**How it fits the parts next to it.** The plate covers the window in the door end wall, above the intake slots and in front of the door, on four M4 screws into the rivet nuts.

**Check before moving on.** Each plug mates with only its own socket.

### 3.11 Wiring

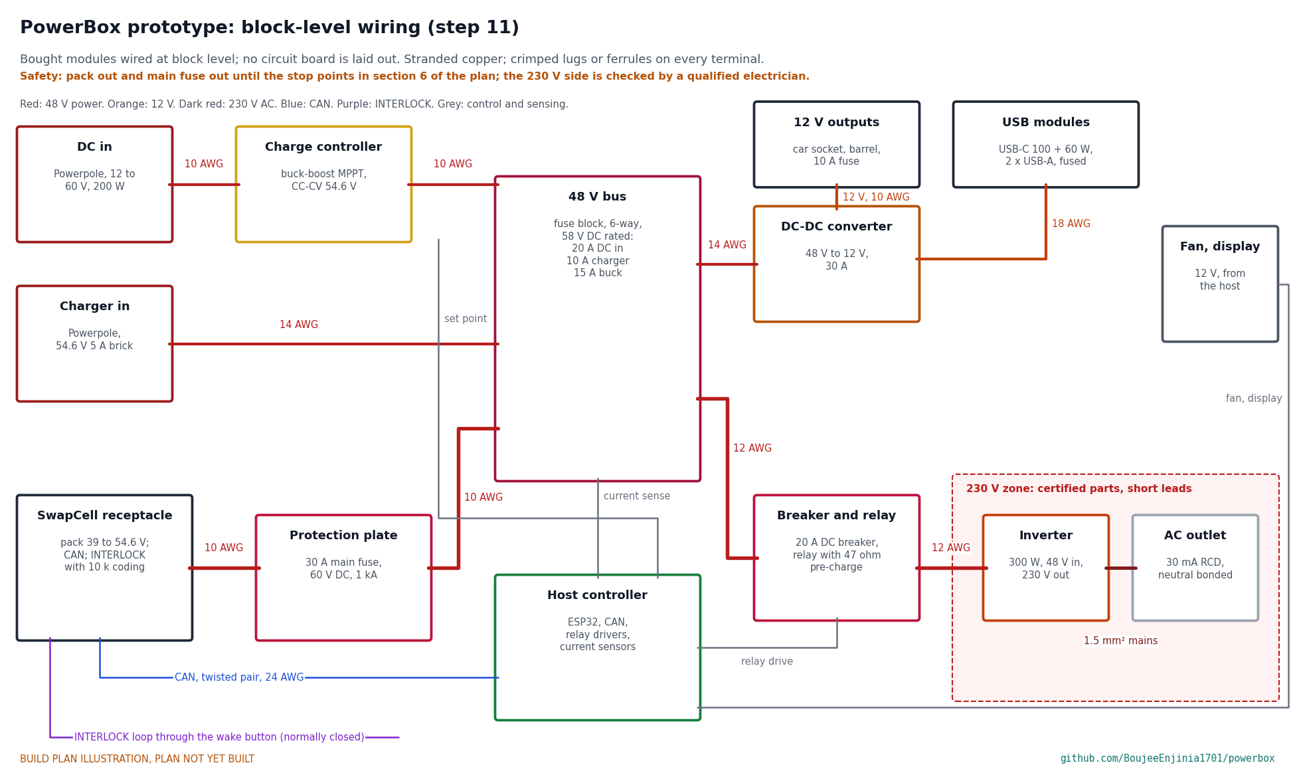
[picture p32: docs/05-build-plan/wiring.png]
Figure 22. Block-level wiring


*Figure 22. Block-level wiring with wire sizes. No circuit board is laid out at this stage; bought modules are wired together.*

Every power module is bought. Buy to these specifications, not to a brand:

*Table 2. Modules to buy.*

| Module | What to buy |
| --- | --- |
| Charge controller | Buck-boost DC-DC, 12 to 60 V in, 200 W, constant current and constant voltage to 54.6 V with the current limit set by the controller board; input surge protection and reverse-polarity protection |
| Controller board | ESP32 with a CAN transceiver and 120 ohm termination, relay drivers and current sensors on the inputs and outputs |
| Inverter | 48 V DC in (40 to 60 V), 300 W continuous, 600 W for 1 s, pure sine, 230 V 50 Hz, output isolated from the DC input so its neutral can be bonded, remote on and off, idle 10 W or less |
| Buck converter | 36 to 60 V in, 12 V 30 A out, about 94 % efficient |
| Fuse block | 6-way blade fuse block rated 58 V DC or more, with 60 V fuses: 15 A converter, 20 A DC in, 10 A charger in, 10 A 12 V sockets, and the USB modules at 10, 7.5 and 5 A |
| Protection parts | 30 A main fuse and holder rated 60 V DC or more with at least 1 kA breaking capacity; 20 A DC breaker; relay with a 47 ohm pre-charge resistor for the inverter |

Wire it like this, with stranded copper and a crimped lug or ferrule on every terminal:

1. Receptacle power pins to the main fuse on the protection plate, and on to the 48 V side of the fuse block: 10 AWG (5.3 mm²).
2. DC in housing to the charge controller input, through its 20 A fuse: 10 AWG. Charge controller output to the fuse block: 10 AWG.
3. Charger in housing to the fuse block through its 10 A fuse: 14 AWG (2.1 mm²).
4. Fuse block to the buck converter through its 15 A fuse: 14 AWG. Buck converter output to the 12 V sockets: 10 AWG to the socket fuse, 14 AWG on to the sockets; to the USB modules: 18 AWG (0.8 mm²).
5. Fuse block through the 20 A breaker and the relay with its pre-charge resistor to the inverter input: 12 AWG (3.3 mm²).
6. Receptacle CAN pins to the controller board: twisted pair, 24 AWG. The 120 ohm termination is on the board.
7. Receptacle INTERLOCK pin through the normally closed wake button and the 10 kilohm coding resistor to signal ground: 24 AWG.
8. Controller board to the relay coil, the current sensors, the charge controller's current set point, the fan and the display: 24 AWG.
9. Inverter output to the AC outlet with its RCD: 1.5 mm² mains cable with an earth, as short as possible, with the inverter's output neutral bonded to the case and to the outlet's earth pin. This step is done or checked by a qualified electrician (section 6).

Keep the 48 V and 230 V wires apart from the signal wires, tie every wire down, and label both ends.

**Check before moving on.** Every wire continues end to end; with no pack in the bay and the main fuse out, the 48 V bus reads open to the case; the polarity of each Powerpole matches the module it feeds, checked with a meter, not by wire colour.

### 3.12 Pack bay door, with its hinge, latch and hasp

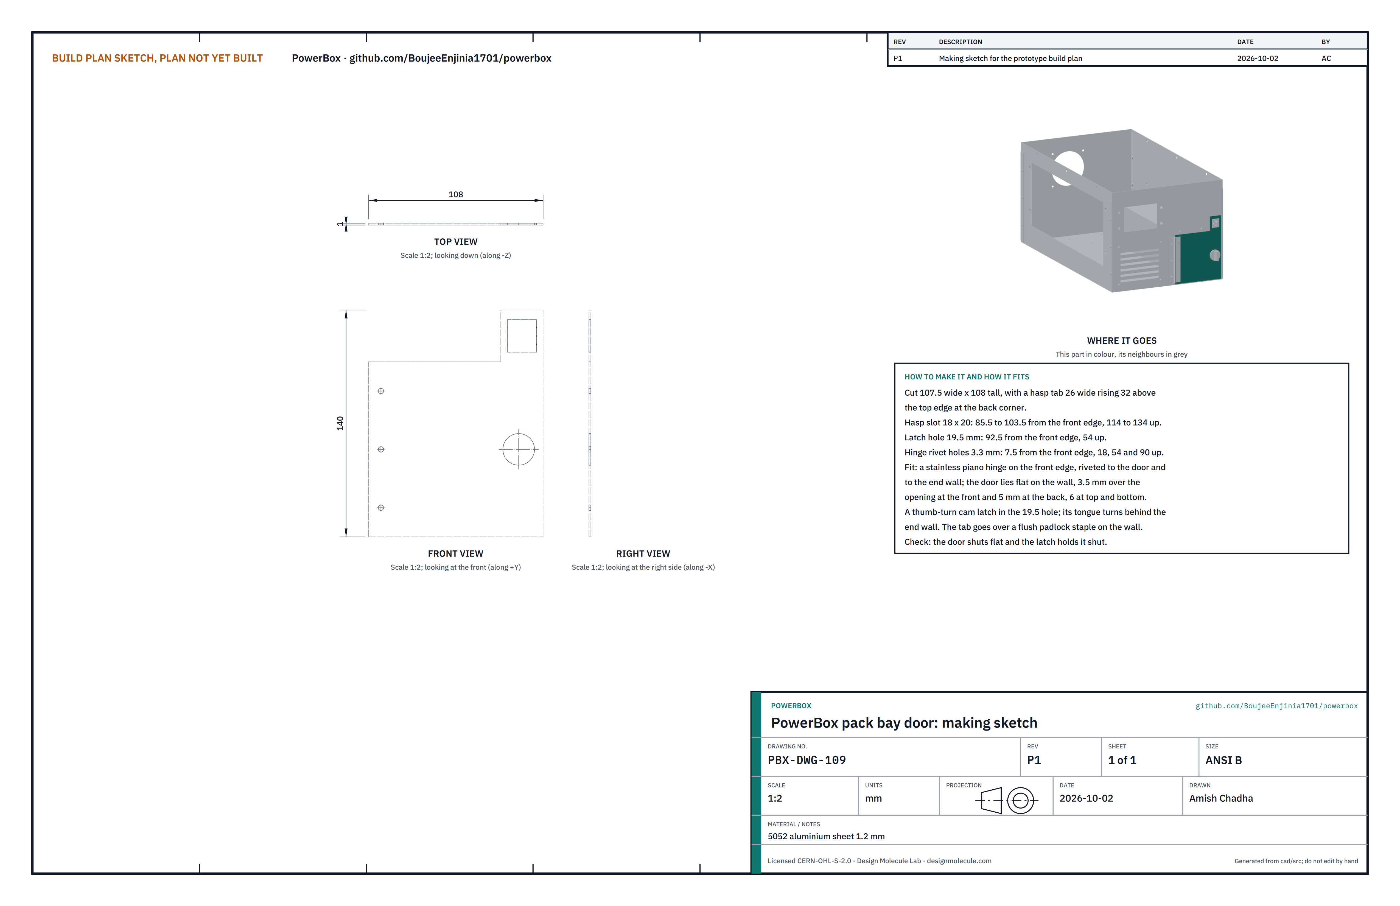
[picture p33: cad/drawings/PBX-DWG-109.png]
Figure 23. Making sketch of the pack bay door


*Figure 23. Pack bay door making sketch (PBX-DWG-109), seen from outside.*

**What it is and what it is made from.** The door over the pack bay. 5052 aluminium sheet 1.2 mm, 107.5 wide and 108 tall, with a hasp tab 26 wide rising 32 above its top edge at the back corner.

**How to make it.**

1. Cut the door with its tab and deburr it.
2. Cut the hasp slot, 18 x 20: 85.5 to 103.5 from the front edge, 114 to 134 up from the bottom edge.
3. Drill the latch hole, 19.5 mm: 92.5 from the front edge, 54 up.
4. Drill the hinge rivet holes, 3.3 mm: 7.5 from the front edge, 18, 54 and 90 up.

**How it fits the parts next to it.**

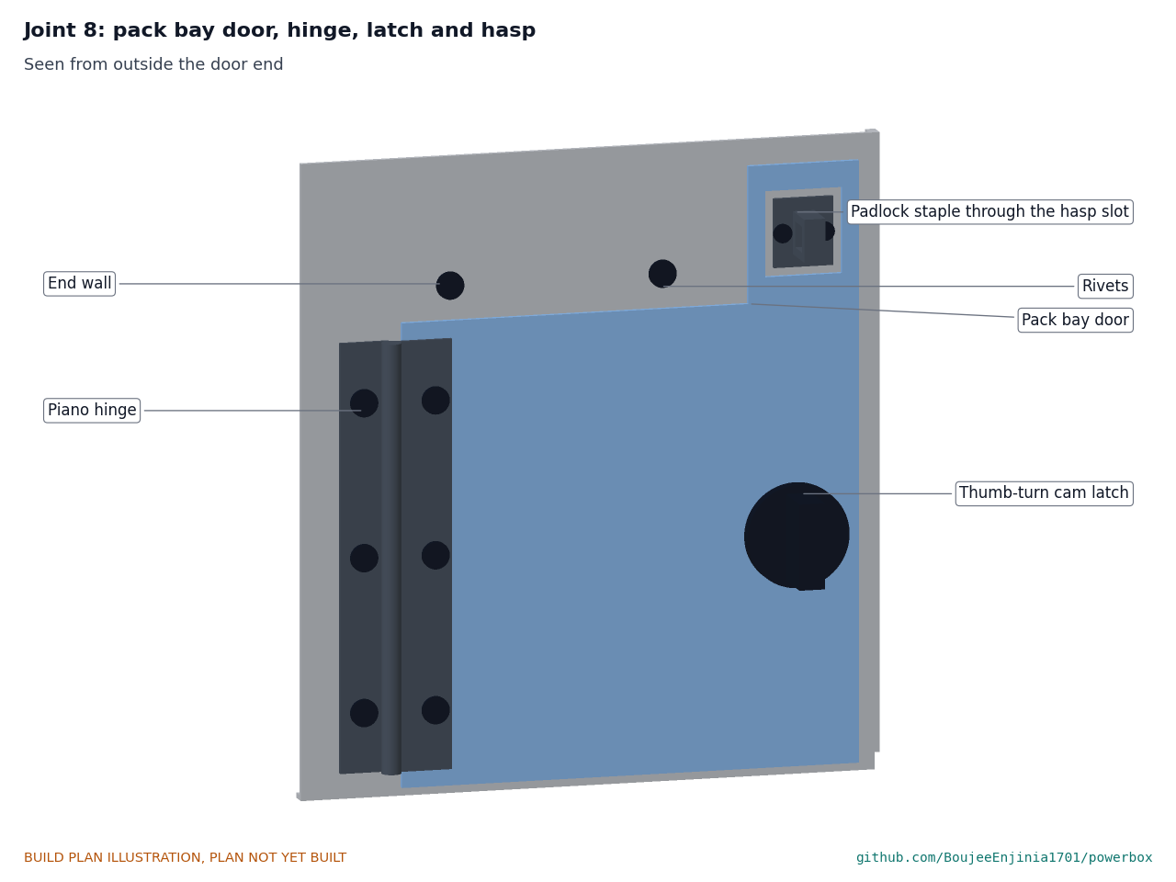
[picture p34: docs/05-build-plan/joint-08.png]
Figure 24. Joint 8: door, hinge, latch and hasp


*Figure 24. Seen from outside: the piano hinge on the front edge, the cam latch, and the hasp tab over the padlock staple.*

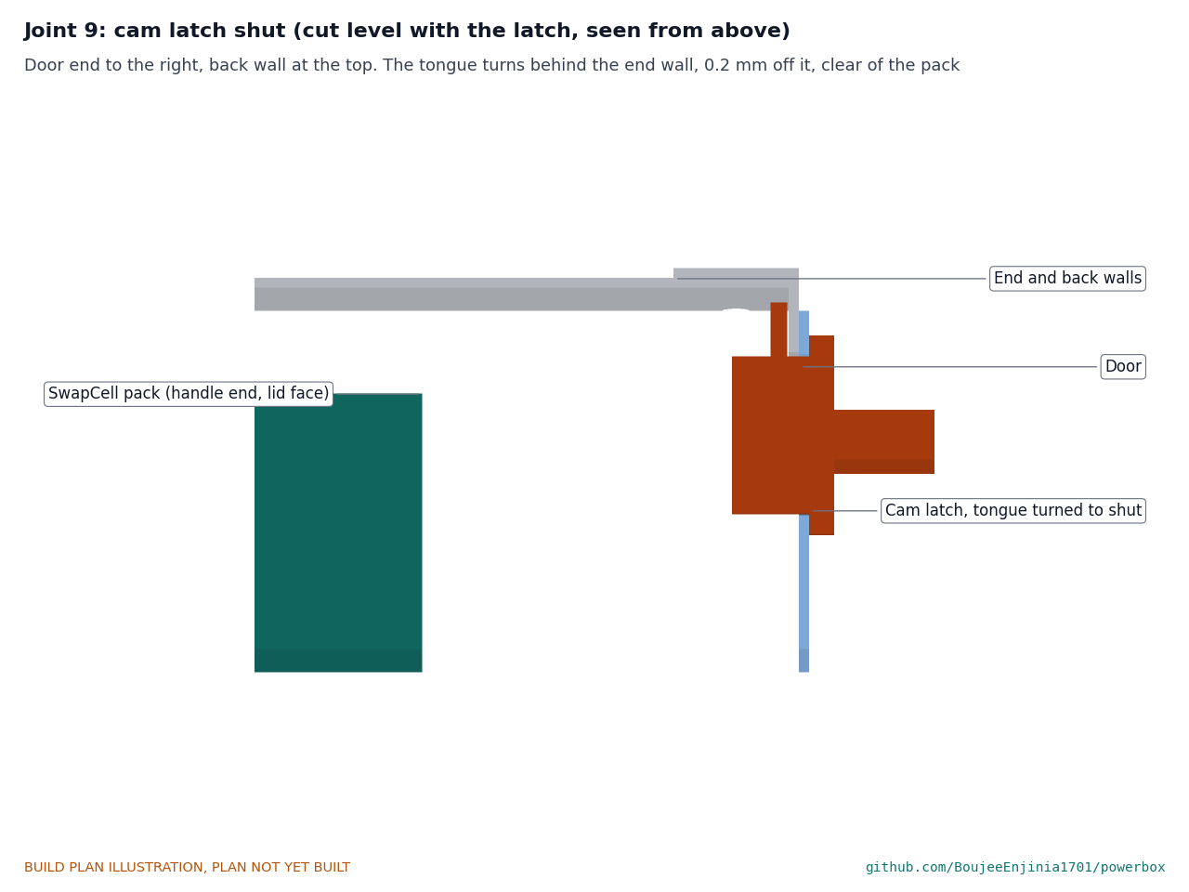
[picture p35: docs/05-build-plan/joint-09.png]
Figure 25. Joint 9: cam latch shut


*Figure 25. Seen from above, cut level with the latch: the latch tongue turns behind the end wall and stays clear of the pack.*

The door lies flat on the outside of the end wall, overlapping the opening by 3.5 at the front, 5 at the back and 6 at top and bottom. A stainless piano hinge on its front edge is riveted to the door and to the wall (three rivets each side). A thumb-turn cam latch in the 19.5 mm hole holds it shut: its tongue turns behind the end wall, 0.2 mm off it. The hasp tab goes over a flush padlock staple riveted to the wall, so a padlock can lock the door. When shut, the door is 10 mm behind the end of the pack's handle and stops the pack if the latch catch ever lets go.

**Check before moving on.** The door shuts flat and the latch holds it; the hinge swings without binding.

### 3.13 Handle doubler plate

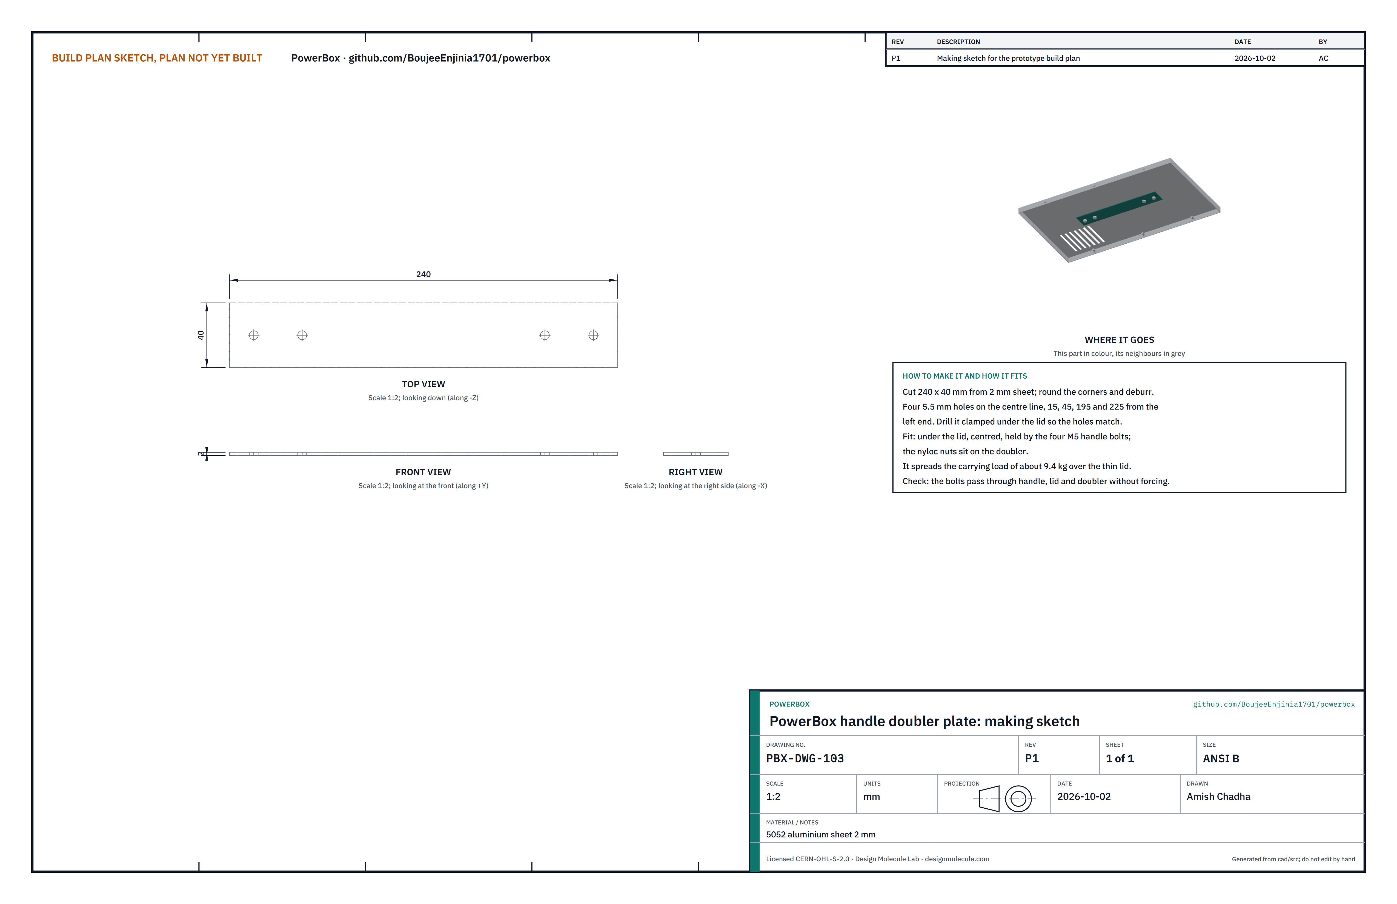
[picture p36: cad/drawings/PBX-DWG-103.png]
Figure 26. Making sketch of the handle doubler plate


*Figure 26. Handle doubler plate making sketch (PBX-DWG-103).*

**What it is and what it is made from.** A strip under the lid that spreads the carrying load. 5052 aluminium sheet 2 mm, 240 x 40.

**How to make it.**

1. Cut the strip, round the corners and deburr it.
2. Drill four 5.5 mm holes on the centre line, 15, 45, 195 and 225 from the left end. Best drilled clamped under the lid, through the lid's holes.

**How it fits the parts next to it.**

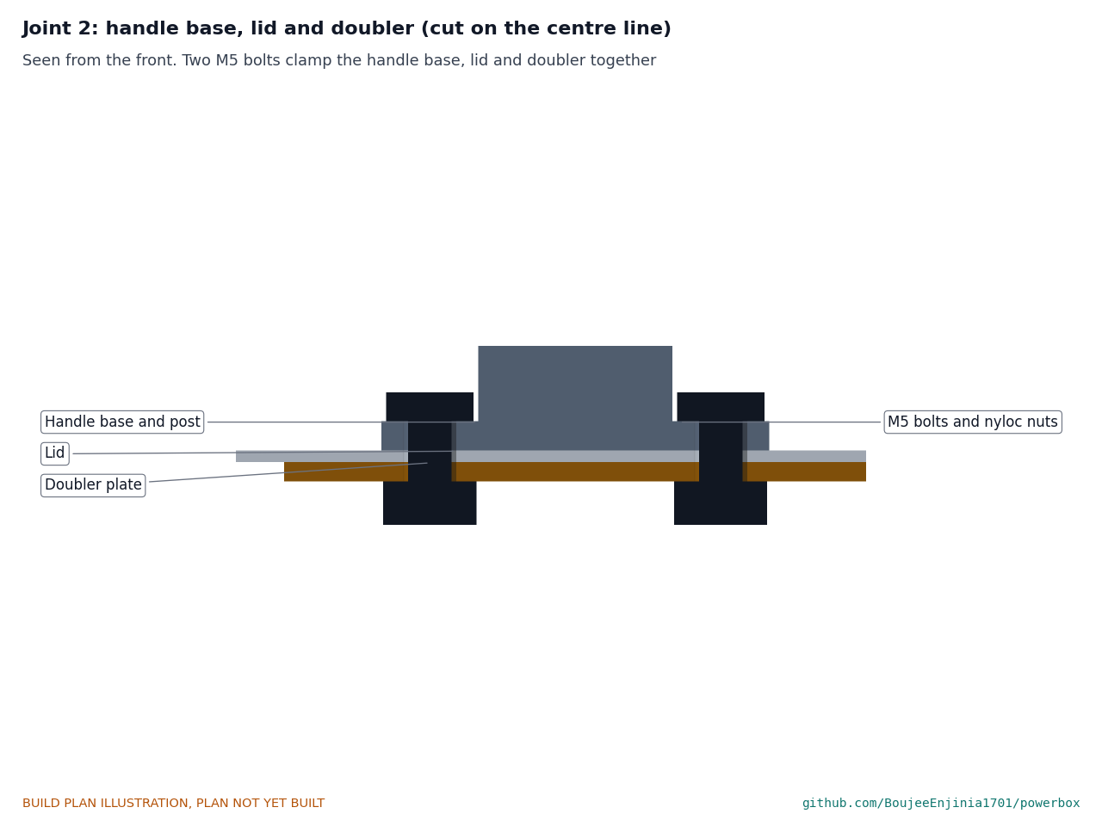
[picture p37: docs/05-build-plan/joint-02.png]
Figure 27. Joint 2: handle, lid and doubler


*Figure 27. Four M5 bolts clamp the handle base plates, the lid and the doubler together; the nyloc nuts sit on the doubler.*

**Check before moving on.** The four bolts pass through handle, lid and doubler without forcing.

### 3.14 Lid

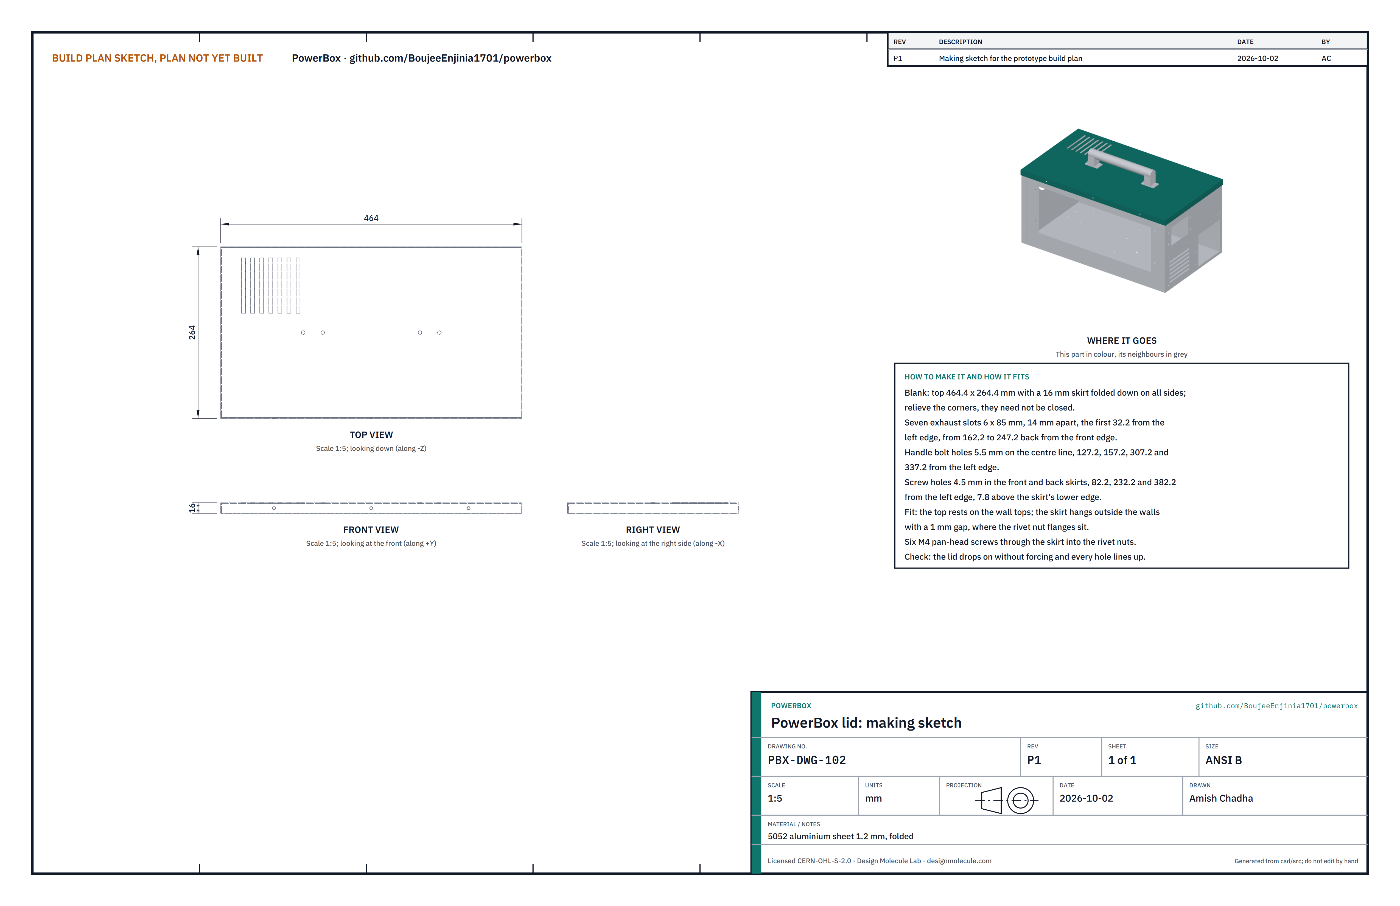
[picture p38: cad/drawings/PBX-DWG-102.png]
Figure 28. Making sketch of the lid


*Figure 28. Lid making sketch (PBX-DWG-102).*

**What it is and what it is made from.** The removable top of the case, with exhaust slots and the handle. 5052 aluminium sheet 1.2 mm, folded: a top 464.4 x 264.4 with a 16 mm skirt on all four sides.

**How to make it.**

1. Cut the blank and relieve the corners; the skirt corners need not be closed. Fold the skirt down on all four sides.
2. Cut seven exhaust slots 6 x 85, 14 apart, the first 32.2 from the left edge, from 162.2 to 247.2 back from the front edge.
3. Drill the handle bolt holes, 5.5 mm, on the centre line at 127.2, 157.2, 307.2 and 337.2 from the left edge.
4. Drill the screw holes, 4.5 mm, in the front and back skirts at 82.2, 232.2 and 382.2 from the left edge, 7.8 above the skirt's lower edge.

**How it fits the parts next to it.**

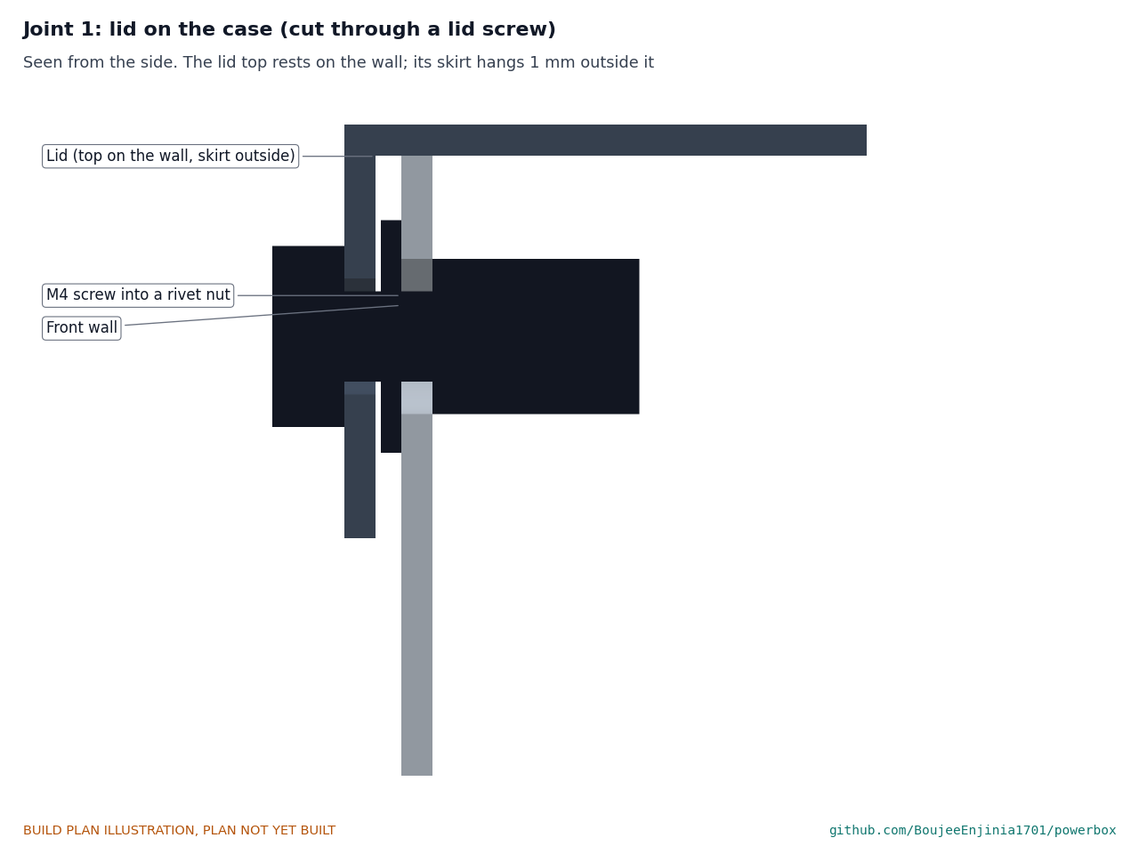
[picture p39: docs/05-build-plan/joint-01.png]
Figure 29. Joint 1: lid on the case


*Figure 29. Cut through a lid screw: the lid top rests on the wall and its skirt hangs 1 mm outside it, where the rivet nut flange sits.*

The top rests on the top edges of all four walls; the skirt hangs outside them with a 1 mm gap. Six M4 pan-head screws go through the skirt into the rivet nuts.

**Check before moving on.** The lid drops on without forcing and every screw hole lines up.

### 3.15 Bought components

Buy to specification, not brand. Line numbers are those of the bill of materials.

- **Carry handle (line 3).** Folding bar handle with two base plates, 200 mm span, rated 15 kg or more.
- **SwapCell pack (line 4).** The SwapCell interface v0.3 reference pack, from the SwapCell project; it is not part of this build's parts.
- **Pack bay parts (line 5).** Class D latch catch; SwapCell receptacle on its floating mount with the 10 kilohm INTERLOCK coding resistor (the SwapCell dock part); M3 and M4 heat-set inserts.
- **Door hardware (line 6).** Stainless piano hinge about 100 long; thumb-turn cam latch for a 19 mm hole that grips 1.2 mm sheet with a tongue about 15 long; flush padlock staple.
- **Power modules (lines 7 to 10).** As Table 2.
- **Output modules (lines 11 to 13).** USB-C power delivery modules (100 W and 60 W), two USB-A modules, a 12 V car socket and a 5.5 x 2.1 mm barrel socket, a snap-in lit rocker main switch (22 x 30 mm panel hole), a recessed normally closed push button for the wake button, a single 230 V outlet with a 30 mA RCD (the national socket of the first partner's country with its earth pin bonded to the case, never a universal multi-standard socket), and a 2.4 inch display.
- **Inputs (line 14).** Two panel-mount Anderson Powerpole PP45 housings with dust caps.
- **Fan (line 15).** 80 mm 12 V fan, about 16 L/s free air, with a finger grille and a washable foam filter pad.
- **Protection and wiring (line 16).** As Table 2, with 10, 12, 14, 18 and 24 AWG stranded wire, 1.5 mm² mains cable, lugs and ferrules.
- **Grid charger (line 17).** A certified 54.6 V, 5 A lithium-ion charger brick with a Powerpole DC lead.
- **Fixings and feet (line 18).** Stainless: 14 M4 rivet nuts and 14 M4 x 10 pan-head screws; 8 M4 x 12 button-head screws for the runners; 8 M4 button-head screws with nyloc nuts for the brackets and protection plate, and 8 more for the inverter and converter; 4 M5 x 16 bolts with nyloc nuts; M3 screws and nuts; about 30 blind rivets 3.2 mm; 4 self-adhesive rubber feet 20 mm across and 8 mm tall; 6 mm nylon standoffs; labels and heat-shrink.

## 4. Putting it together

In each picture the parts already fitted are grey and the part being fitted is in colour, with an arrow showing the way it goes in.

### Step 1: floor runners onto the floor

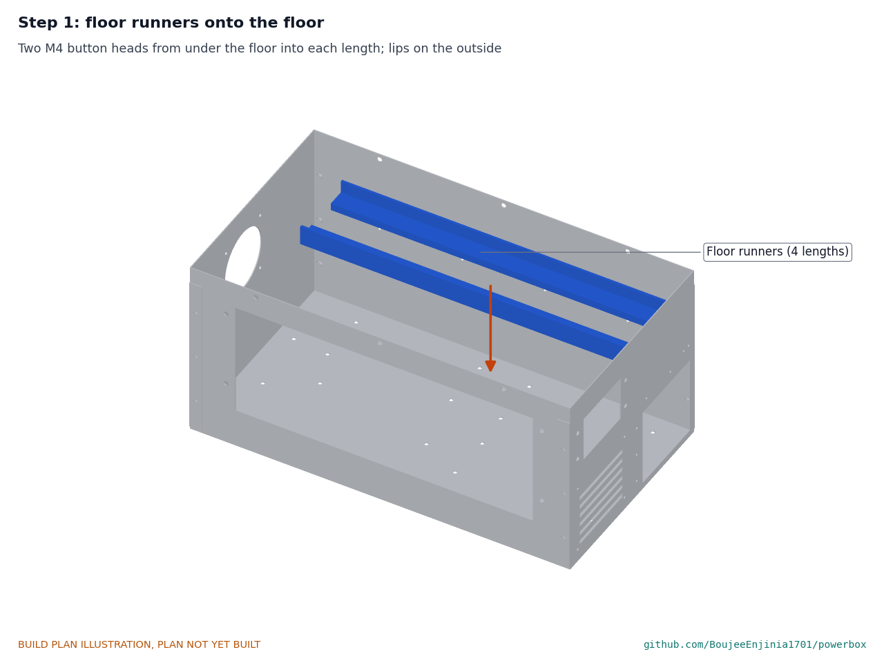
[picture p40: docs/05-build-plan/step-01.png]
Step 1


Two M4 button-head screws from under the floor into each length's inserts, lips on the outside of the bay, snug. A drop of medium threadlocker on each.

### Step 2: catch bracket and receptacle bracket

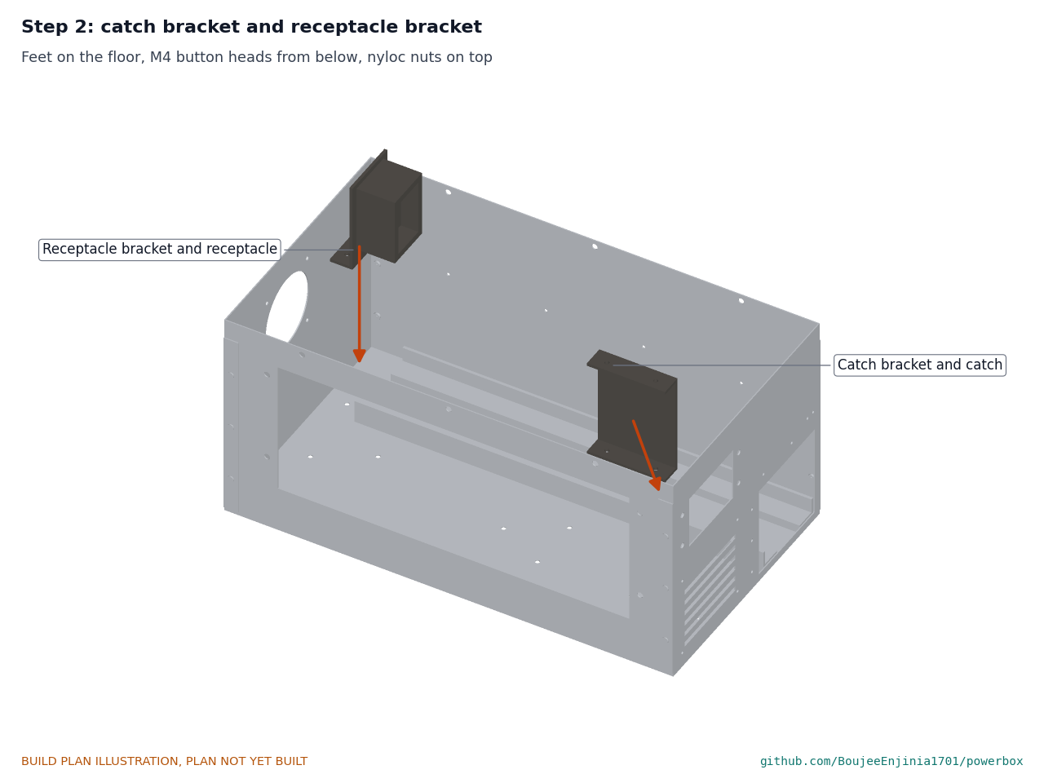
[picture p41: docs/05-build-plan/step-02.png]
Step 2


The catch bracket with its catch, flanges to the front, and the receptacle bracket with its receptacle, foot toward the fan end. Two M4 button-head screws from below each, nyloc nuts on top. Leave the catch bracket's screws loose until step 6.

### Step 3: inverter, converter, protection plate and fuse block

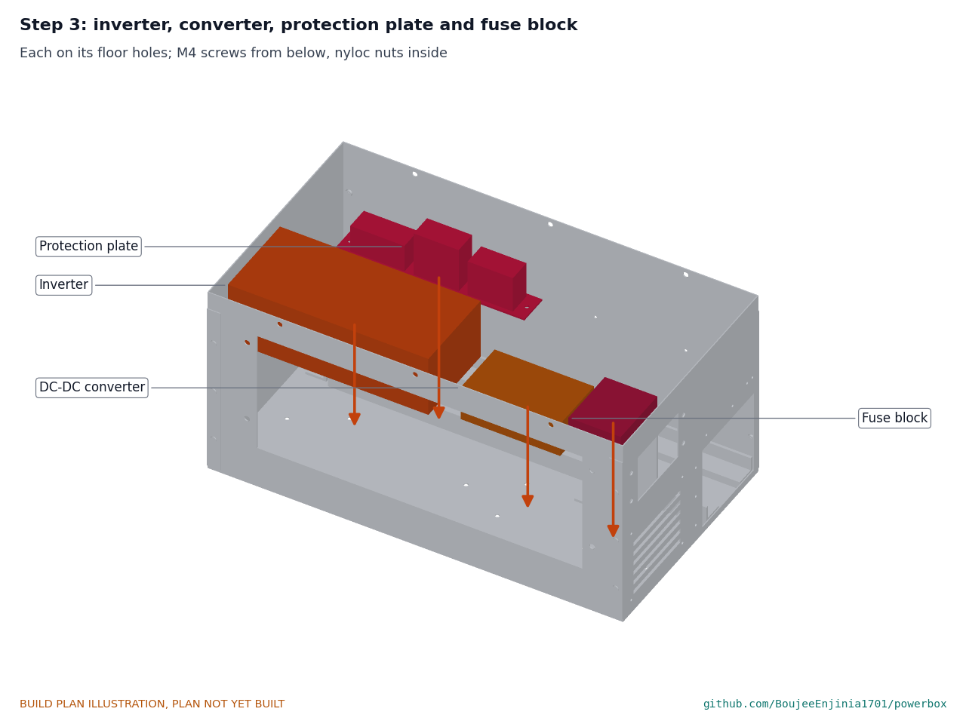
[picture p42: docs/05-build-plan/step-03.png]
Step 3


Each on its floor holes with M4 screws from below and nyloc nuts inside. **Hold point:** the main fuse stays out of its holder.

### Step 4: fan, grille and intake filter frame

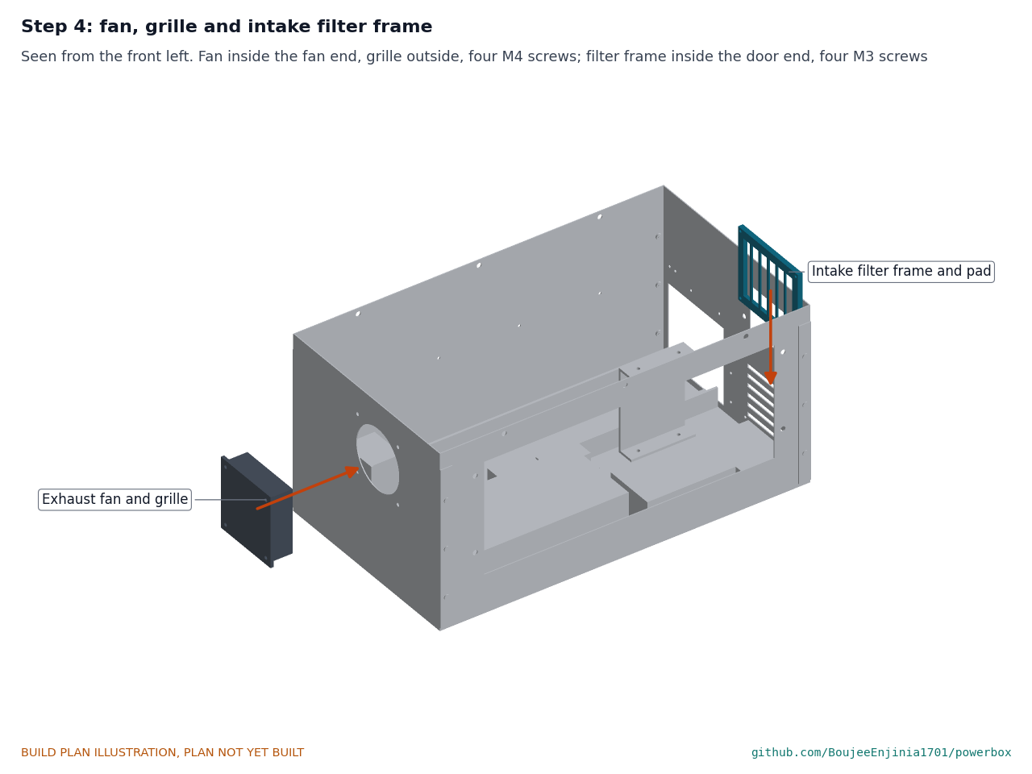
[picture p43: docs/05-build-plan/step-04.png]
Step 4


The fan inside the fan end, blowing out, the grille outside, four M4 screws through both. The filter frame and pad inside the door end on four M3 screws.

### Step 5: top guide rail onto the shelf

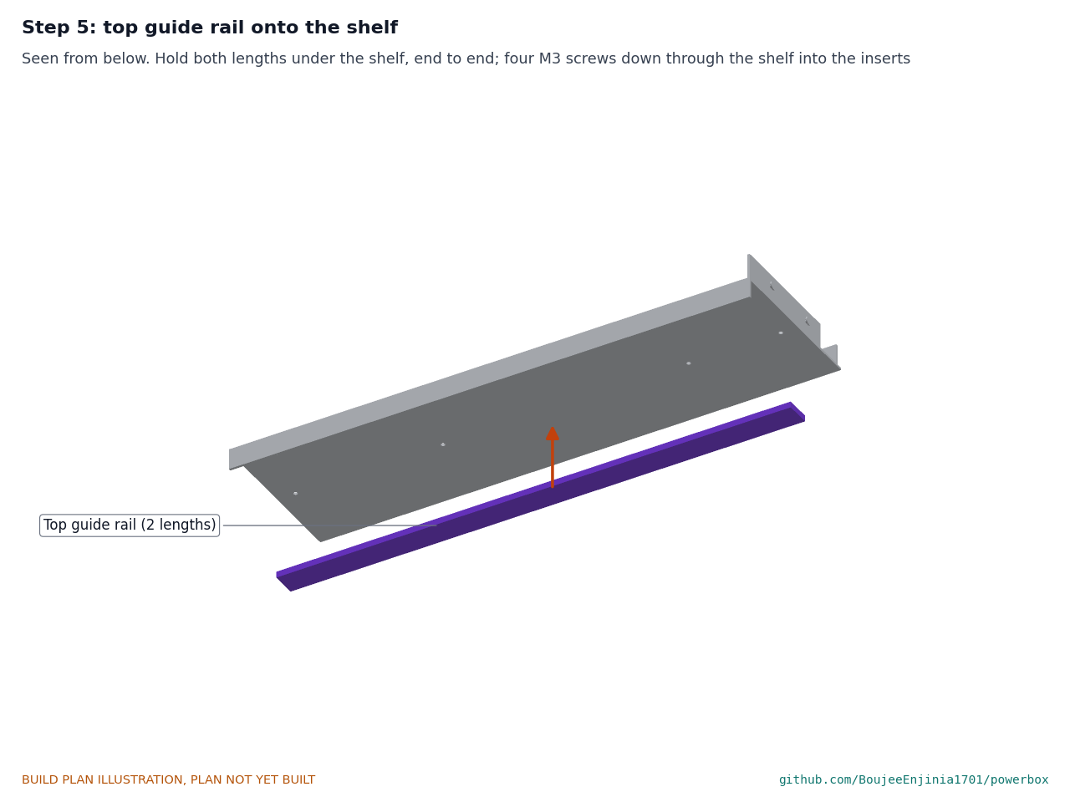
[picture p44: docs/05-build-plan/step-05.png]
Step 5


Hold both rail lengths under the shelf, end to end; four M3 screws down through the shelf into the inserts.

### Step 6: shelf into the case

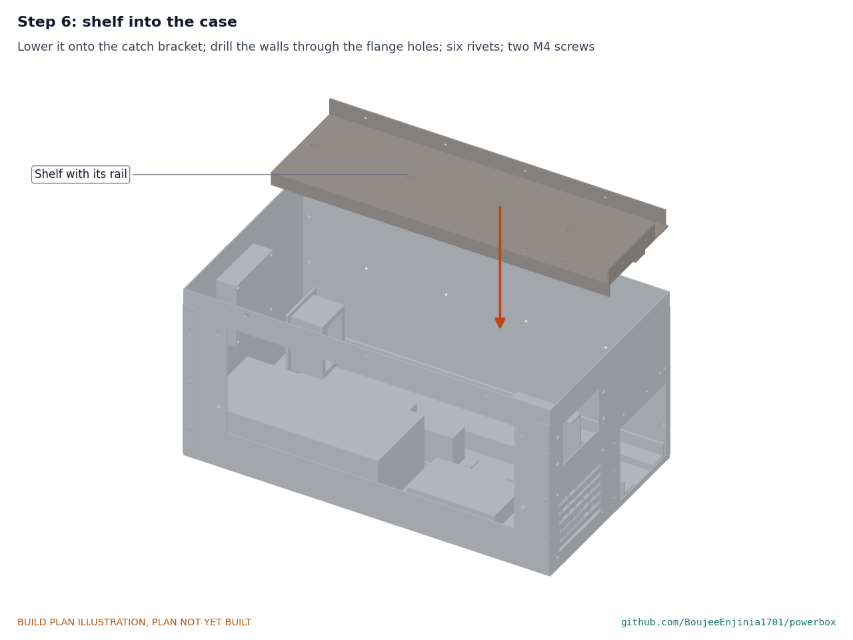
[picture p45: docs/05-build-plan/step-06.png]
Step 6


Lower the shelf onto the catch bracket. Clamp the flanges to the walls, drill through any rivet holes not yet drilled, and set six blind rivets. Two M4 screws down through the shelf into the catch bracket; then tighten the catch bracket's floor screws.

### Step 7: charge controller and host onto the shelf

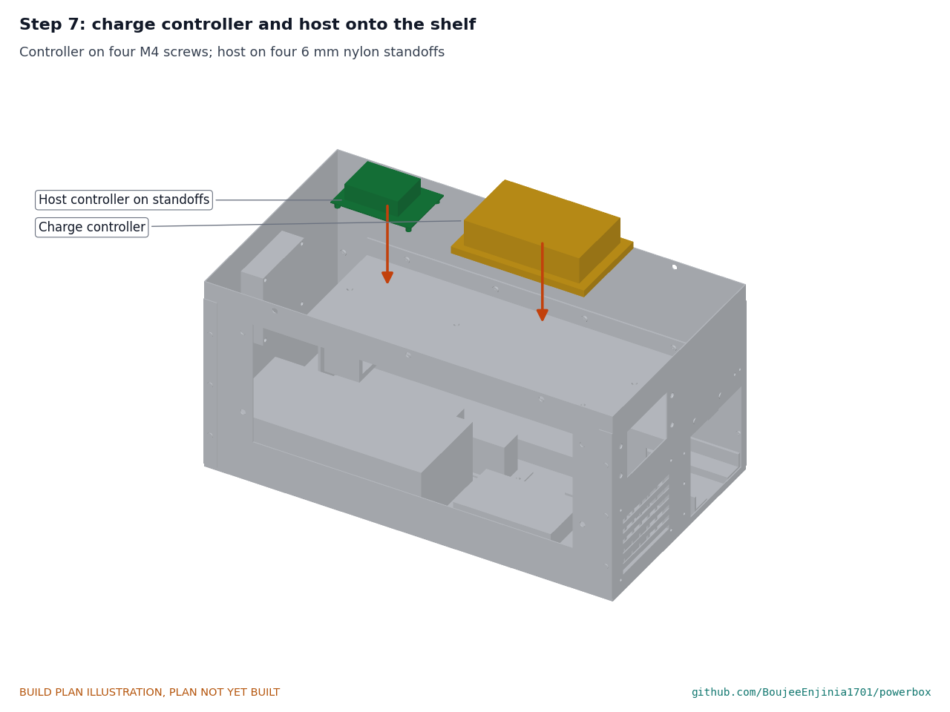
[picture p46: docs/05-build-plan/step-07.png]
Step 7


The charge controller on four M4 screws through the shelf, heat sink up; the controller board on four 6 mm nylon standoffs.

### Step 8: modules into the output panel plate

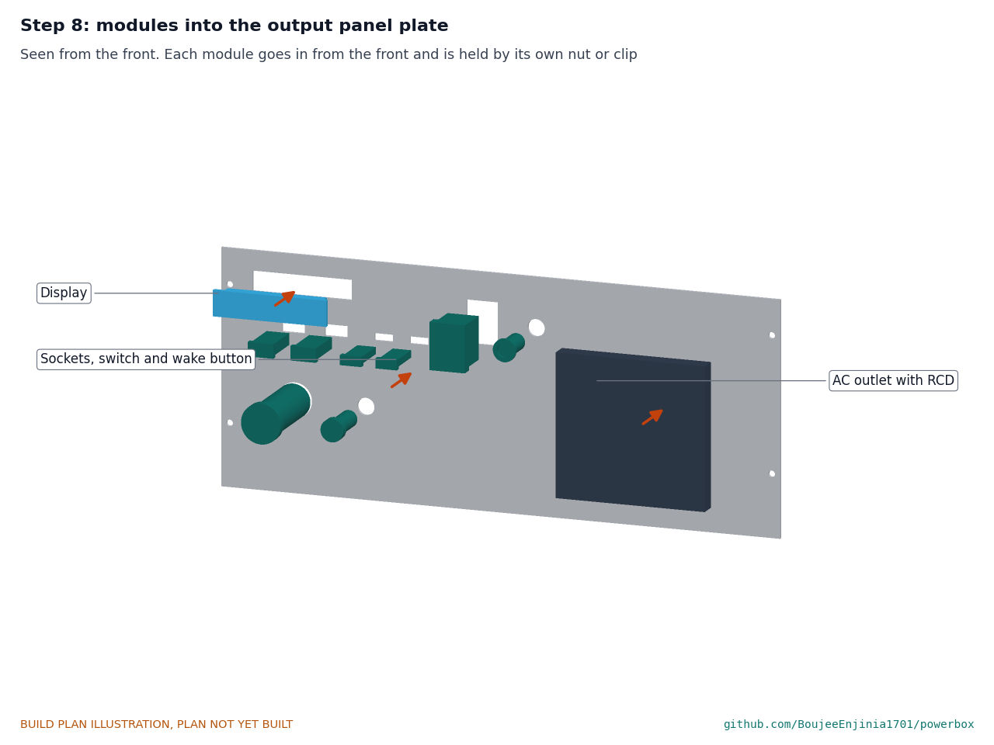
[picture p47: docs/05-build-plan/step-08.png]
Step 8


With the plate on a soft cloth, fit each module from the front with its own nut or clip.

### Step 9: output panel onto the front wall

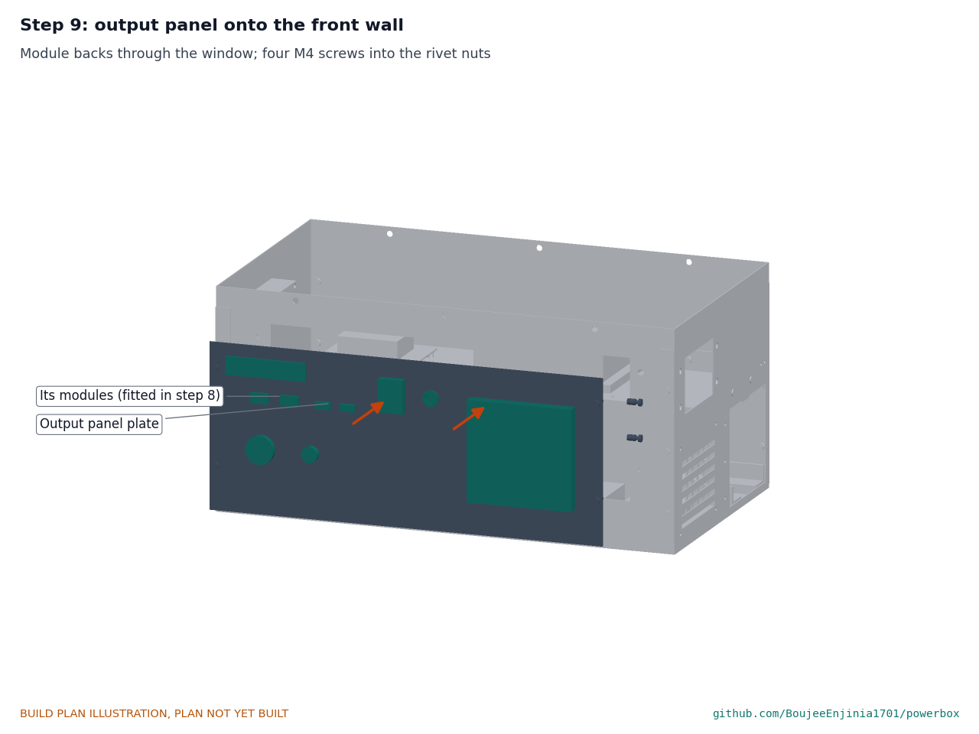
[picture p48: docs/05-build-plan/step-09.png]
Step 9


Feed the module bodies through the window; four M4 screws into the rivet nuts.

### Step 10: input panel onto the door end

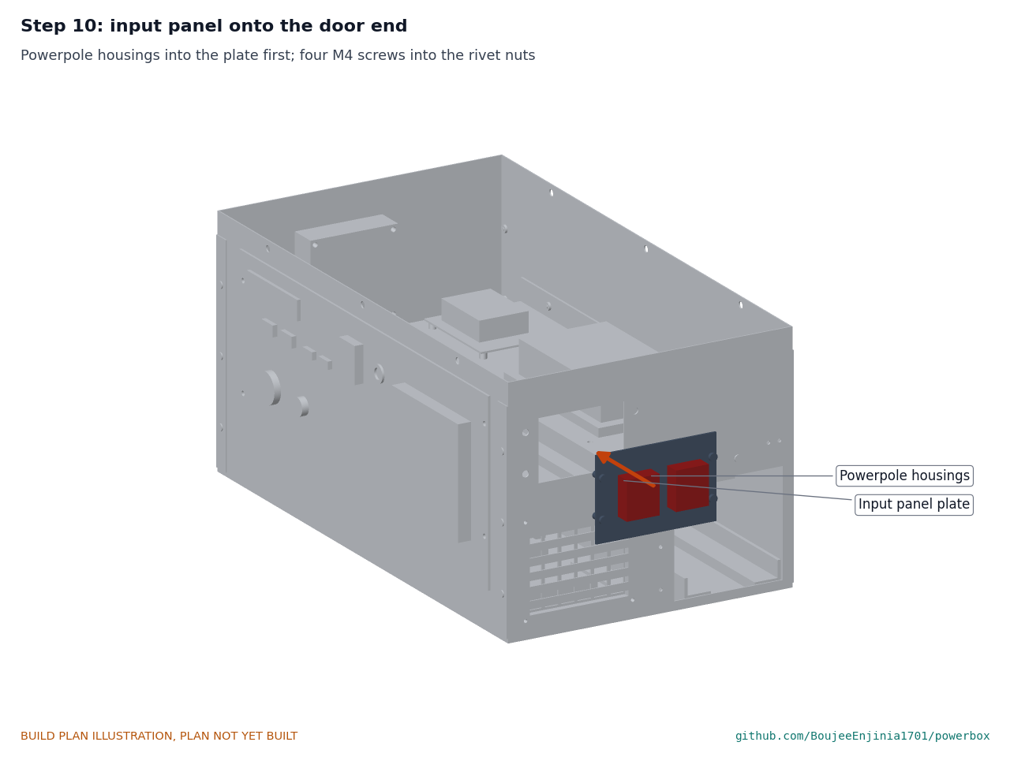
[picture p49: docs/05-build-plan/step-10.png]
Step 10


Four M4 screws into the rivet nuts, DC in at the front.

### Step 11: wiring

Step 11

Wire the modules as section 3.11 and Figure 22. **Hold point:** the wiring checks of section 3.11 pass, and the 230 V side has been checked by a qualified electrician, before going on.

### Step 12: pack bay door

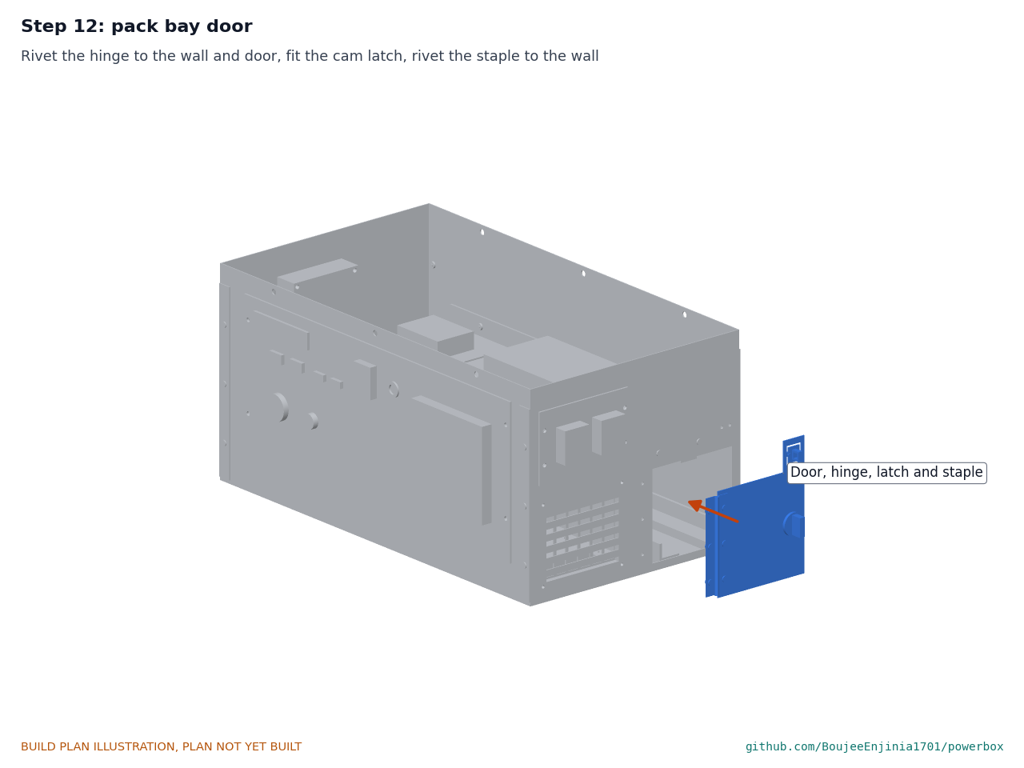
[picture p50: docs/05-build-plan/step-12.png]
Step 12


Rivet the piano hinge to the end wall and to the door, fit the cam latch through the door, and rivet the padlock staple to the wall so it comes through the hasp slot.

### Step 13: handle and doubler onto the lid

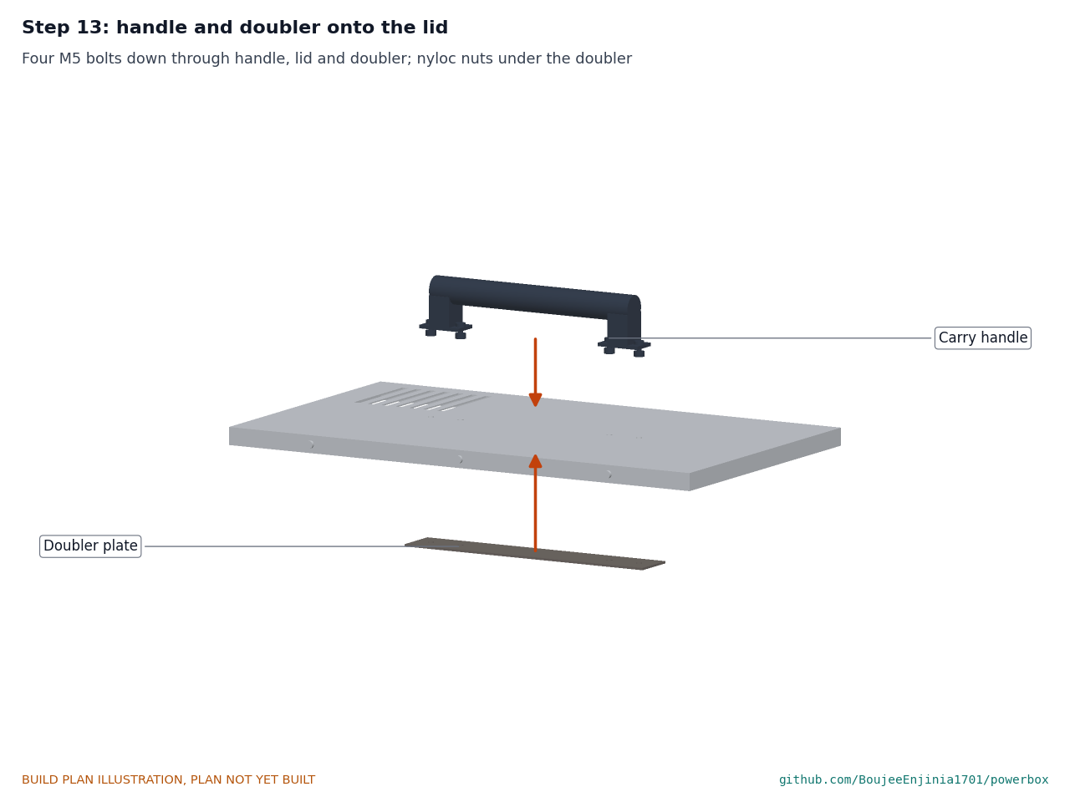
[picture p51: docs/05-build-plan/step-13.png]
Step 13


Four M5 bolts down through the handle base plates, the lid and the doubler; nyloc nuts under the doubler, tight.

### Step 14: lid onto the case

Step 14

Check no wire lies across the wall tops. Lower the lid over the walls; six M4 screws through the skirt into the rivet nuts.

### Step 15: rubber feet

Step 15

Clean the underside with alcohol; one foot at each corner, clear of the screw heads.

### Step 16: the pack into its bay

Step 16

**Hold point:** safety stops S1 to S4 of section 6. Open the door, slide the pack in connector first on the runners until the catch clicks, shut the door and turn the latch.

## 5. First checks

These are the checks a TRL 4 test report would record; this plan only lists them. Requirement numbers are those of PBX-REQ-001.

*Table 3. First checks.*

| Check | Requirement | How | Pass when |
| --- | --- | --- | --- |
| Pack fit and swap | R12 | Slide a pack in and out ten times; time one swap | Plug enters without touching; catch clicks; door shuts; swap 30 s or less |
| Insulation and back-feed | R9 | With no pack, meter between the 48 V bus and the case, and between each AC pin and the DC side | Open circuit everywhere; no AC inlet on the case |
| Keyed inputs | R3, R9 | Try each plug in each input | Each plug mates only with its own input |
| First power | R12 | Bench supply at 48 V with a 0.5 A limit in place of the pack, through the main fuse | Controller board starts, display shows; current under the limit |
| Wake | R12 | Pack in; let it sleep; press the wake button | Pack wakes through the INTERLOCK loop and the display reads its state of charge |
| 12 V and USB outputs | R7 | Load each output to its rating in turn | 12 V within 5 %; USB-C negotiates 100 W and 60 W; no fuse opens |
| AC outlet | R7, R9 | Electrician present; switch the inverter on with a 100 W lamp, then press the RCD test button | 230 V pure sine; pre-charge relay closes without a spark; the RCD trips |
| DC input charging | R3, R5, R6 | Bench supply at 12 V, 36 V and 60 V with a current limit at the DC in | Charging starts; input and output power read for efficiency; net charge 5.0 A or less |
| Grid charging | R4 | The charger brick at the charger in | Charge current 5 A or less; charging ends at 54.6 V |
| Standby | R8 | Measure pack current with outputs off and display on, then off | Ready 1.0 W or less; inverter off after 10 min below 5 W |
| Heat | R7 | Full output while charging for 30 min | The fan starts; the case stays hand-warm; no derating message |
| Mass and size | R10 | Weigh with the pack; measure | 10 kg or less (9.4 kg estimated); 500 x 300 x 280 mm or less |

## 6. Safety stops

Stop at each point. Carry on only when everything listed is true.

- **S1. Before the pack comes into the workshop.** The pack is the SwapCell reference pack with its own battery management, undamaged, dry and not swollen, with its fuse in place. A charging spot is ready on a non-combustible surface (ceramic tile or steel tray), away from exits, with a fire extinguisher for electrical fires and a smoke alarm in the room.
- **S2. Before the main fuse goes in.** With no pack in the bay, the 48 V bus reads open to the case; every fuse and the breaker are rated 60 V DC or more (58 V for the blade fuse block); the receptacle's polarity matches the main fuse and fuse block, checked with a meter, not by wire colour.
- **S3. Before any 230 V is made.** A qualified electrician has checked the wiring from the inverter to the outlet, the neutral bond to the case and earth pin, and that the inverter's output is isolated from its input. The AC outlet is never connected to a wall socket, household wiring, a distribution board or a transfer switch, and no double-male cord is ever made.
- **S4. Before the first charge.** First power and wake checks of section 5 have passed on the bench supply. The first charge is attended the whole time, lid off and case on the charging spot; stop if any part becomes too hot to hold or smells.
- **S5. Before running the inverter at full load.** The fan runs, the intake filter is clean, and the case stands in open air, never in a cupboard or bag.
- **S6. Before the prototype leaves the bench.** The lid screws, handle bolts and door latch are tight; no sharp edge is exposed; the warning labels (standalone only, no back-feed, lithium battery) are on the case.

## 7. Tools, skills and workspace

**Tools.** Sheet metal shop for the case, lid and shelf folds (or a box-and-pan folder 500 mm wide for 1.2 mm aluminium); hand folder or vice with bending bars for the 3 mm brackets; drill press and cordless drill; drills 3.3 to 6.0 mm, step drill to 20 mm and a 19 mm and 76 mm hole saw; files and deburring tool; nibbler or jigsaw with a metal blade for the windows; hand rivet nut tool for M4; hand blind rivet tool; 3D printer with a 220 mm bed that prints PETG; soldering iron for the heat-set inserts; scriber, square, steel rule and calipers; crimp tools for lugs and ferrules; wire strippers; multimeter; bench power supply with a current limit (0 to 60 V, 0 to 5 A); clamp meter; torque screwdriver; scale to 15 kg; stopwatch.

**Skills.** Sheet metal marking, drilling, cutting and riveting; basic 3D printing; crimping and low-voltage DC wiring; safe handling of lithium-ion packs. The 230 V side (inverter output to outlet and RCD) needs a qualified electrician to do or check it; everything else is extra-low voltage (54.6 V or less).

**Workspace.** A bench about 1.5 x 0.75 m; a metalwork area kept apart from the electronics so swarf stays off the modules; the charging spot of S1; ventilation for printing PETG.

**Personal protective equipment.** Safety glasses for cutting, drilling and riveting; cut-resistant gloves for sheet metal; hearing protection for the nibbler or jigsaw; no gloves near a turning drill; insulated tools for the battery and bus work.

## 8. Where the numbers come from

- Model and constructability checks: `cad/src/model.py` (`python cad/src/model.py --check`, 64 checks); STEP and STL exports in `cad/step/` and `cad/stl/`.
- Pictures: `cad/src/build_plan_media.py`, using `.kit/build_views.py`; written to `docs/05-build-plan/` and `cad/drawings/PBX-DWG-101` to `PBX-DWG-113`.
- General arrangement: `cad/drawings/PBX-DWG-001.pdf`, Rev P2.
- Calculations: `docs/04-calcs/01-sizing.md` (PBX-CAL-001 v0.2) and `docs/04-calcs/sizing.py`; mass and size section 10, protection section 6, thermal section 9.
- Bill of materials: `bom/bom.csv` and `bom/bom-notes.md`.
- Decisions: `docs/decisions/0003-design-for-construction.md` (PBX-DDR-003), with PBX-DDR-001 and PBX-DDR-002; register `docs/06-design-decisions.md` (PBX-DEC-001).
- Requirements: `docs/03-requirements.md` (PBX-REQ-001 v0.5).

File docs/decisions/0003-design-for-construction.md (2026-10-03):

---
doc_id: PBX-DDR-003
title: PowerBox design for construction
project: PowerBox
doc_type: Design decision record
version: "0.3"
status: Draft
date: '2026-10-02'
author: Amish Chadha
license: CERN-OHL-S-2.0
revisions:
- version: "0.1"
  date: '2026-10-01'
  author: Amish Chadha
  change: Changes that make the concept physically buildable, with the reason for each; made under Amish's 2026-09-30 instruction to make the design physically buildable; open for his review
- version: "0.2"
  date: '2026-10-02'
  author: Amish Chadha
  change: "Accepted by Amish on 2026-10-02 (Tables 1 to 3); record stays Draft"
- version: "0.3"
  date: '2026-10-02'
  author: Amish Chadha
  change: "Cost line updated to USD 483 with the lit rocker switch; follow-up on the renders marked done (appearance model updated; renders made on Amish's Mac)"
---

# 0003: Design for construction

- **Date:** 2026-10-01
- **Status:** accepted. Every change in Table 1 was made under Amish's 2026-09-30 instruction to make the design physically buildable. Amish, 2026-10-02: "i approve your recommendations for all 555 open decisions." This covers every change in Tables 1 and 2 and the recommendations in Table 3 (A1 to A4), recorded in the design decisions register (PBX-DEC-001, items 1 to 4). The record stays Draft.

## Context

On 2026-09-30 Amish asked for a build plan that shows how each component is made and how it fits the next, with pictures, and wrote: "If you are realising that the design cannot be built as per concept - fix the design assumptions to match and be physically feasible as you draw the illustrations." The TRL 3 model of PBX-PRC-001 showed what PowerBox does and passed a clash check, but many of its parts could not be made or fixed as drawn: the lid sat on the 1.2 mm wall edges with nothing to locate or hold it, the SwapCell pack floated 1 mm above its runners with nothing guiding its sides, the shelf and catch bracket stood on edges with no fixing, the receptacle hung in the air, the door was a solid 6 mm block with no hinge, and the panels were blocks on a solid wall with nowhere for the module bodies to go.

The changes below keep what PowerBox does: the same case size, pack position and SwapCell interface v0.3 (station host, coded INTERLOCK, class D catch and door as second stop), the same electronics, outputs, inputs and safety arrangement. Nothing here changes the pitch or the safety case. Every change is in `cad/src/model.py`, which now runs 64 constructability checks (`python cad/src/model.py --check`): no two of its 45 components overlap, every part that must touch its support does, every clearance is at least the stated value, and the pack slides out through the end opening on its runners without touching anything else. All 64 pass.

## Decision

*Table 1. Changes made to the model, the BOM and the calculations.*

| # | Problem in the concept | Change made | Why this way |
| --- | --- | --- | --- |
| P1 | The lid was a tray sitting butt on the 1.2 mm wall edges, with no location and no fixing. | The lid top rests on the wall tops and its skirt, now 16 mm deep, hangs outside the walls with a 1 mm gap. Six M4 pan-head screws go through the front and back skirts into rivet nuts set in the walls 7 mm below their top edge. | The skirt locates the lid on all four sides and the 1 mm gap takes the rivet nut flanges. The lid is still removable for service. The case is 3 mm lower overall because the lid no longer stands on top of the walls. |
| P2 | The carry handle stood on the 1.2 mm lid with no fixing and nothing to spread the load. | A bought folding handle with two base plates, held by four M5 bolts through the lid and a 2 mm aluminium doubler plate (240 x 40 mm) underneath, nyloc nuts on the doubler. | The doubler spreads the 9.4 kg carrying load over the thin lid; the load passes through the lid screws into the walls. |
| P3 | The pack floated 1 mm above the floor runners, nothing guided its front and back faces, and the 419 mm runners were too long for a common 3D printer and had no fixing. | Four printed PETG runner lengths (209.4 mm each) with an L section: the pack rests on the 24 mm bases, and 3 mm lips stand 1 mm off its latch face and lid face. Each length is held by two M4 button-head screws from under the floor into heat-set inserts. The top guide rail is printed in two lengths and screwed up into the shelf with M3 screws. | The pack now sits on its runners and is guided on three sides with the 1 mm clearance of the concept. Two short lengths fit a 220 mm printer bed. |
| P4 | The shelf was a 4 mm slab resting only on the catch bracket, with no fixing. | A 2 mm folded aluminium shelf: a 20 mm rear flange and a 20 mm end flange folded up and riveted to the back and door end walls (six 3.2 mm blind rivets), a 15 mm front flange folded down for stiffness, and two M4 screws into the catch bracket's top flange. | Supported on three edges and fixed on all of them; folding 2 mm sheet is a sheet shop job, 4 mm is not. |
| P5 | The catch bracket was a 6 mm plate standing on its edge on the floor, with no fixing. | A 3 mm folded aluminium channel, 80 mm long: its foot is screwed to the floor with two M4 screws and its top flange to the shelf with two more. The class D catch bolts to its web. | The bracket that takes the pack's latch load is now fixed at both ends; the web stays 2 mm in front of the pawl as before. |
| P6 | The SwapCell receptacle hung in the air at the end of the bay. | A 3 mm folded aluminium angle bracket on the floor at the fan end, two M4 screws; the receptacle screws to its web through its floating mount. | Holds the receptacle where the concept put it; the floating mount still lets it meet the plug. |
| P7 | The door was a 6 mm block with a pull and no hinge. A magnetic catch has nowhere to go: there are 5 mm between the pack's lid face and the edge of the opening, and 9 mm of wall behind the opening. | A 1.2 mm aluminium door hinged on its front edge with a stainless piano hinge riveted to the wall and the door; a thumb-turn cam latch through the door whose tongue turns behind the end wall; and a hasp tab at the door's top back corner over a flush padlock staple riveted to the wall. | The front edge has 32 mm of wall for the hinge, the back edge only 9 mm. The cam latch holds the door shut where a magnet cannot fit, and the padlock eye of the concept becomes a hasp and staple. The closed door still stops the pack handle (10 mm clear). |
| P8 | The output and input panels were 4 mm blocks on solid walls; the bodies of the sockets, outlet and display had nowhere to go, and the 12 V socket body would have met the inverter. | A window in each wall (360 x 140 mm in the front wall, 78 x 55 mm in the door end) covered by a 2 mm aluminium panel plate held by four M4 screws into rivet nuts. Each module sits in a cut-out in its plate and its body passes through the window. The 12 V socket and barrel socket move up 15 mm so the socket body clears the inverter by 17 mm. | Bought modules mount in a flat plate, as they are made to; the plate can be cut and labelled before it goes on the case. |
| P9 | The inverter and buck converter had no fixings, and the main fuse, inverter breaker, relay and pre-charge resistor and the 6-way fuse block (BOM line 16) had no place in the case. | Floor holes for the inverter's and converter's feet; a 2 mm protection plate (210 x 34 mm) on the floor between the inverter and the pack bay carrying the main fuse holder, breaker and relay; the fuse block on the floor beside the converter; the host on four 6 mm nylon standoffs. | Every part has a fixing, and the protection parts sit on the short path from the receptacle to the inverter. |
| P10 | The folded tub's corners were not closed. | The end walls carry 15 mm tabs that fold onto the outside of the long walls, three blind rivets each. | A corner any sheet shop can fold and a builder can rivet, with no welding of 1.2 mm aluminium. |
| P11 | The intake filter had no holder, and the fan's four screws would have fallen on the ends of the exhaust slots. | A printed filter frame on four M3 screws inside the door end, holding a washable foam pad over the intake slots. The six exhaust slots behind the fan become one 76 mm hole, with the fan's four holes on a 71.5 mm square around it and the bought grille outside. | The frame holds and releases the pad; the round hole gives the fan about 4,500 mm² of open area, twice the slots it replaces. |
| P12 | Screws under the floor would stop the case standing flat; the rubber feet of BOM line 18 were not modelled. | Four self-adhesive rubber feet, 20 mm across and 8 mm tall, at the corners of the underside. | The screw heads (2.2 mm) sit inside the height of the feet. |

*Table 2. Knock-on changes.*

| Item | Change | Reason |
| --- | --- | --- |
| Mass | 9.42 kg with the pack (was 8.61 kg), 0.58 kg under R10's 10 kg (PBX-CAL-001 v0.2, Table 4). | The shelf, brackets, runners, panel plates, door hardware and fixings drawn with real thickness. |
| Size | 480 x 279 x 275 mm overall (was 482 x 276 x 278 mm); R10 still met with 5 mm to spare in height. | Lid over the walls, 8 mm feet, panel plates. |
| Cost | Value-engineering target: USD 450. Estimated cost of the constructable design: USD 483 (USD 33 over the target); the concept was USD 449. BOM lines 1, 2, 3, 5, 6, 15, 16 and 18 repriced. | Parts added for construction. |
| Thermal | Unchanged: the same heat sources, fan and intake area; the exhaust open area behind the fan rises from about 2,100 to 4,500 mm². | |
| Drawings | PBX-DWG-001 Rev P2; making sketches PBX-DWG-101 to 113 added. | Follows the model. |
| Documents | PBX-CAL-001 v0.2, PBX-REQ-001 v0.5, PBX-PRC-001 v0.6: mass, size and cost; the budget is reported as a value-engineering target. No requirement changed status except R11, now reported against its target. | Follows the model. |

*Table 3. Proposed, then accepted by Amish as recommended on 2026-10-02.*

| # | Question | Options | Recommendation |
| --- | --- | --- | --- |
| A1 | Which edge the door hinges on. The product renders show a back-edge hinge (REVIEW 2026-09-26, item 3); the constructable design hinges on the front edge, so the door opens toward the back of the case. | (a) front edge, as modelled; (b) back edge, which needs the opening narrowed or the case made deeper. | (a): it is the only edge with room for the hinge. Accepted 2026-10-02; the renders are updated to the front-edge hinge. |
| A2 | The cam latch is a thumb turn. Theft resistance is still open (PBX-DDR-001 item 15). | (a) thumb turn plus the padlock hasp, as modelled; (b) a keyed cam latch, about USD 3 more. | (a) for the prototype; decide with item 15. Accepted 2026-10-02; a keyed cam latch (about USD 3) if the first partner runs an unattended or shared charging point (PBX-DEC-001, item 3). |
| A3 | The R10 mass margin is now 0.58 kg on estimated masses. | (a) accept and weigh the prototype at TRL 4; (b) look for mass now (1.5 mm panel plates, lighter runner infill). | (a). Accepted 2026-10-02; weigh at TRL 4. |
| A4 | Whether to accept the design for construction as a whole. | (a) accept P1 to P12; (b) accept with changes. | (a). Accepted 2026-10-02. |

## Consequences

- `design_state: constructable` in `project.yaml`. The build plan PBX-BLD-001 shows every component and step in pictures generated from the model (`cad/src/build_plan_media.py`).
- The photoreal renders (`media/render-*.png`), `media/card.png`, `media/social-preview.png` and the appearance model `cad/src/product_model.py` the appearance model `cad/src/product_model.py` was updated on 2026-10-02 to this design (lid skirt, door hinged on its front edge with no window, lit rocker main switch, bare aluminium case, 76 mm fan hole, 8 mm feet; PBX-DEC-001, items 9, 11 and 12). The photoreal renders, card and social preview are remade on Amish's Mac from the exported scenes.
- Several bought parts must be checked against their datasheets when they are chosen at TRL 4 (the design decisions register PBX-DEC-001 lists them): hole patterns of the catch, receptacle mount, inverter and converter feet, cam latch grip, panel cut-outs, and the voltage rating of the fuse block.

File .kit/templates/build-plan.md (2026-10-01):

---
doc_id: PRJ-BLD-001
title: Project prototype build plan
project: Project name
doc_type: Build plan
version: "0.1"
status: Draft
date: YYYY-MM-DD
author: Amish Chadha
license: CERN-OHL-S-2.0
revisions:
  - version: "0.1"
    date: YYYY-MM-DD
    author: Amish Chadha
    change: First build plan; design made constructable
---

# Project prototype build plan

**Plan, not yet built.** How to build the first proof-of-concept prototype, component by component. Building and testing to it is TRL 4 work. Decisions still to be made are kept in the design decisions register (`docs/06-design-decisions.md`), not here.

## 1. What you are building

Every component, pulled apart and numbered in build order

One short paragraph: what the prototype is, how many components, which are made and which are bought, and the main ways they are made.

## 2. What changed to make it buildable

| Component | The concept had | The buildable design has | Why |
| --- | --- | --- | --- |

## 3. Making the components

### 3.1 Component name

Making sketch

**What it is and what it is made from.**

**How to make it.**

1. Mark out ...
2. Cut ...

**How it fits the parts next to it.**

Close-up of the joint

**Check before moving on.**

## 4. Putting it together

### Step 1: ...

Step 1

## 5. First checks

| Check | Requirement | How | Pass when |
| --- | --- | --- | --- |

## 6. Safety stops

## 7. Tools, skills and workspace

## 8. Where the numbers come from

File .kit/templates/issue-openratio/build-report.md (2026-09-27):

---
name: Build report
about: Tell us what happened when you built, printed or tested part of this design
title: "Build report: "
labels: build-report
---

This is a research and educational prototype, not a medical device. It is a TRL 3 concept and is not released for fabrication. If you build any part of it, you do so at your own risk. Reports help everyone.

**What you built** (part, sub-assembly or test)

**Materials, tools and settings**

**What worked**

**What did not work, with photos or measurements if you have them**

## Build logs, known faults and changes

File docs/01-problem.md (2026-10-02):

---
doc_id: PBX-PRB-001
title: PowerBox problem statement
project: PowerBox
doc_type: Problem statement
version: "0.5"
status: Draft
date: '2026-10-02'
author: Amish Chadha
license: CERN-OHL-S-2.0
revisions:
- version: "0.1"
  date: '2026-09-24'
  author: Amish Chadha
  change: Initial scaffold
- version: "0.2"
  date: '2026-09-24'
  author: Amish Chadha
  change: Populate to TRL 2 (users, context, constraints, out of scope, prior work)
- version: "0.3"
  date: '2026-09-24'
  author: Amish Chadha
  change: Removed StepGen as a charging source after StepGen became a walking vehicle (Amish, 2026-09-24)
- version: "0.4"
  date: '2026-09-25'
  author: Amish Chadha
  change: TRL 3. SwapCell interface v0.3, budget scope and AC region decided by Amish (PBX-DDR-001); open questions updated
- version: "0.5"
  date: '2026-10-02'
  author: Amish Chadha
  change: "Open questions on the first partner, theft resistance and R2 answered by Amish's 2026-10-02 decisions"
---

# PowerBox problem statement

When the power goes out, households need a small, safe store of electricity for lights, phones, radio and internet, charged from whatever source is available: a solar panel, the grid when it is up or a charged pack brought home from an e-bike. Design with, not for: requirements must come from co-design sessions and field trials with the intended users through a local partner.

## The problem

Outages are routine for a large share of the world. Grids with scheduled load shedding, storm-exposed distribution lines and informal connections leave households dark for hours, often in the evening when lighting and phone charging matter most. The fallback is usually a kerosene lamp, candles, a car battery on an unsafe charger, or a petrol generator, which is noisy, costly to run and a carbon monoxide hazard indoors.

Commercial portable power stations solve part of this, but they have three gaps for these users:

- **Closed, sealed batteries.** When the cells wear out, the whole unit is usually discarded. The pack cannot be swapped, shared or repaired.
- **Charging assumes a working grid or a large solar array.** Few charge well from a small panel, and none are designed to share a battery with an e-bike or a village charging hub.
- **Overselling.** Marketing implies a box can run a fridge or kettle. A household that buys on that promise and then drains the battery in an hour loses trust in the whole category.

PowerBox is a standalone power station built around the portfolio's SwapCell pack, so the same battery can move between a PowerBox, a SunSpoke e-bike and a SwapCell dock. It charges from a solar panel, the grid or a charged pack brought home from the bike, and it is honest about scale: a 200 W panel delivers about 634 Wh to the pack on a clear day, and one pack runs lights, phones, a radio and a router through an outage, not a fridge or a kettle.

## Users and context

| User | Need | Context |
| --- | --- | --- |
| Outage-prone urban and peri-urban household | Evening light, phone charging, radio and home internet through a 2 to 6 h outage, recharged from the grid when it returns | Load shedding or storm outages; small homes and flats; indoor use |
| Off-grid rural household | A daily store for lights and phones, charged from a small solar panel; a pack that can travel on an e-bike to a charging hub | No grid, or an unreliable mini-grid; dust, heat, rough transport |
| Household in an informal settlement | Safe light and phone charging without unsafe improvised wiring or kerosene; low purchase cost; theft-resistant design | Dense housing, fire risk, shared walls, limited space |
| Community charging point operator | Charge many phones and lamps for a small fee; swap packs between boxes and a charging hub; see how much energy each pack delivered | Market stall, school, clinic waiting room, community centre |
| Local technician or repair shop | Open design, standard parts, a pack and modules that can be diagnosed and replaced | Informal electronics repair trade |
| Open hardware community | A reference design that ties SwapCell, SunSpoke and StepGen (a walking vehicle on the same pack) together | Makerspaces, university labs, NGOs |

## Constraints

- Garage-buildable prototype. Budget $450 USD for the PowerBox parts, excluding the SwapCell pack, which is priced once in the SwapCell project (decided by Amish, 2026-09-25).
- Built around SwapCell interface v0.3: 13S lithium-ion pack, 46.8 V nominal (39.0 to 54.6 V), 468 Wh nameplate, 340 x 90 x 80 mm body (393 mm overall), blind-mate connector with CAN, wake through a 10 kΩ coded INTERLOCK loop (item W), a station host type with a charge-discharge mode (item C) and latch classes (item V). PowerBox must not change the interface locally; conflicts go back to SwapCell.
- Standalone only. PowerBox must never connect to household wiring, a wall outlet or a distribution board. Back-feeding endangers line workers and is illegal almost everywhere.
- Carryable by one adult: a case with a single handle, small enough for a shelf or under a bed.
- Safe indoors: lithium cells, a mains-voltage AC outlet and hot power electronics all sit in a living space, often near children.
- Off-the-shelf modules where possible (certified charger brick, inverter, DC-DC converters), so no custom mains electronics are designed at portfolio level.
- DC bus kept below 60 V so the battery side stays in the extra-low-voltage range.
- Operating range about 0 to 40 °C ambient, with charging inhibited by the SwapCell BMS outside its limits.

## Out of scope

- Connection to household wiring in any form, including transfer switches, double-male plug cords and grid-tie inverters.
- Loads above about 300 W, or with high starting surges: refrigerators, freezers, kettles, irons, hair dryers, space heaters, pumps and power tools.
- Whole-home backup and multi-day autonomy for large loads.
- Design of the SwapCell pack, the SunSpoke bike or the StepGen walking vehicle; PowerBox uses the SwapCell interface they share.
- Design of new mains-voltage electronics. The inverter and grid charger are certified off-the-shelf units.

## Prior work

- Commercial portable power stations from several brands (lithium iron phosphate or NMC, 250 to 2,000 Wh) show the product form and output mix users expect: USB-C PD, USB-A, 12 V car socket and pure sine AC. Almost all have sealed, non-swappable batteries.
- Pay-as-you-go solar home systems, widely deployed in East and West Africa and South Asia, show that 20 to 100 Wh per day of lights, phone charging and radio transforms evening life, and that honest sizing matters.
- Battery-swap networks for two- and three-wheelers show that a shared, standard pack can be charged centrally and carried home.
- Open-source battery management and power electronics projects (for example open BMS designs used by the e-bike and solar DIY communities) provide starting points for the host controller and CAN handling.

No link is given where a specific reference has not been verified.

## Open questions

- Which users to involve first, and through which partner (an NGO running community charging points, a solar home system distributor, or a university group in an outage-prone city)? Decided by Amish, 2026-10-02: a partner in a 230 V, 50 Hz region that runs or supplies community charging or solar home systems where outages are routine; the first candidate type to approach is a solar distribution charity such as SolarAid, which works in Zambia and Malawi. Nothing is agreed.
- AC region first: 230 V 50 Hz with a 30 mA RCD. Decided by Amish, 2026-09-25 (PBX-DDR-001); 120 V 60 Hz is a later variant.
- Is theft resistance (a lockable pack door) a priority for informal settlement and community charging users? Decided by Amish, 2026-10-02: a thumb-turn cam latch with a padlock hasp for the prototype, and a keyed cam latch where the partner runs an unattended or shared charging point.
- Is one pack for 1.87 evenings enough, or should the reference evening change? R2 was restated as 1.8 evenings by Amish on 2026-10-02 (PBX-DDR-001 item 13); the reference evening is still to be checked with the first partner's users.

## User research and co-design

This design is for communities the author is not part of, so requirements come from the people who will use it.

- [ ] Identify a local partner organization (Helpful Engineering network, NGO or university)
- [ ] Run co-design sessions with intended users; record who, where and what was learned
- [ ] Validate load, distance, terrain and cost assumptions in the field
- [ ] Revise requirements (REQ) from findings before freezing the design

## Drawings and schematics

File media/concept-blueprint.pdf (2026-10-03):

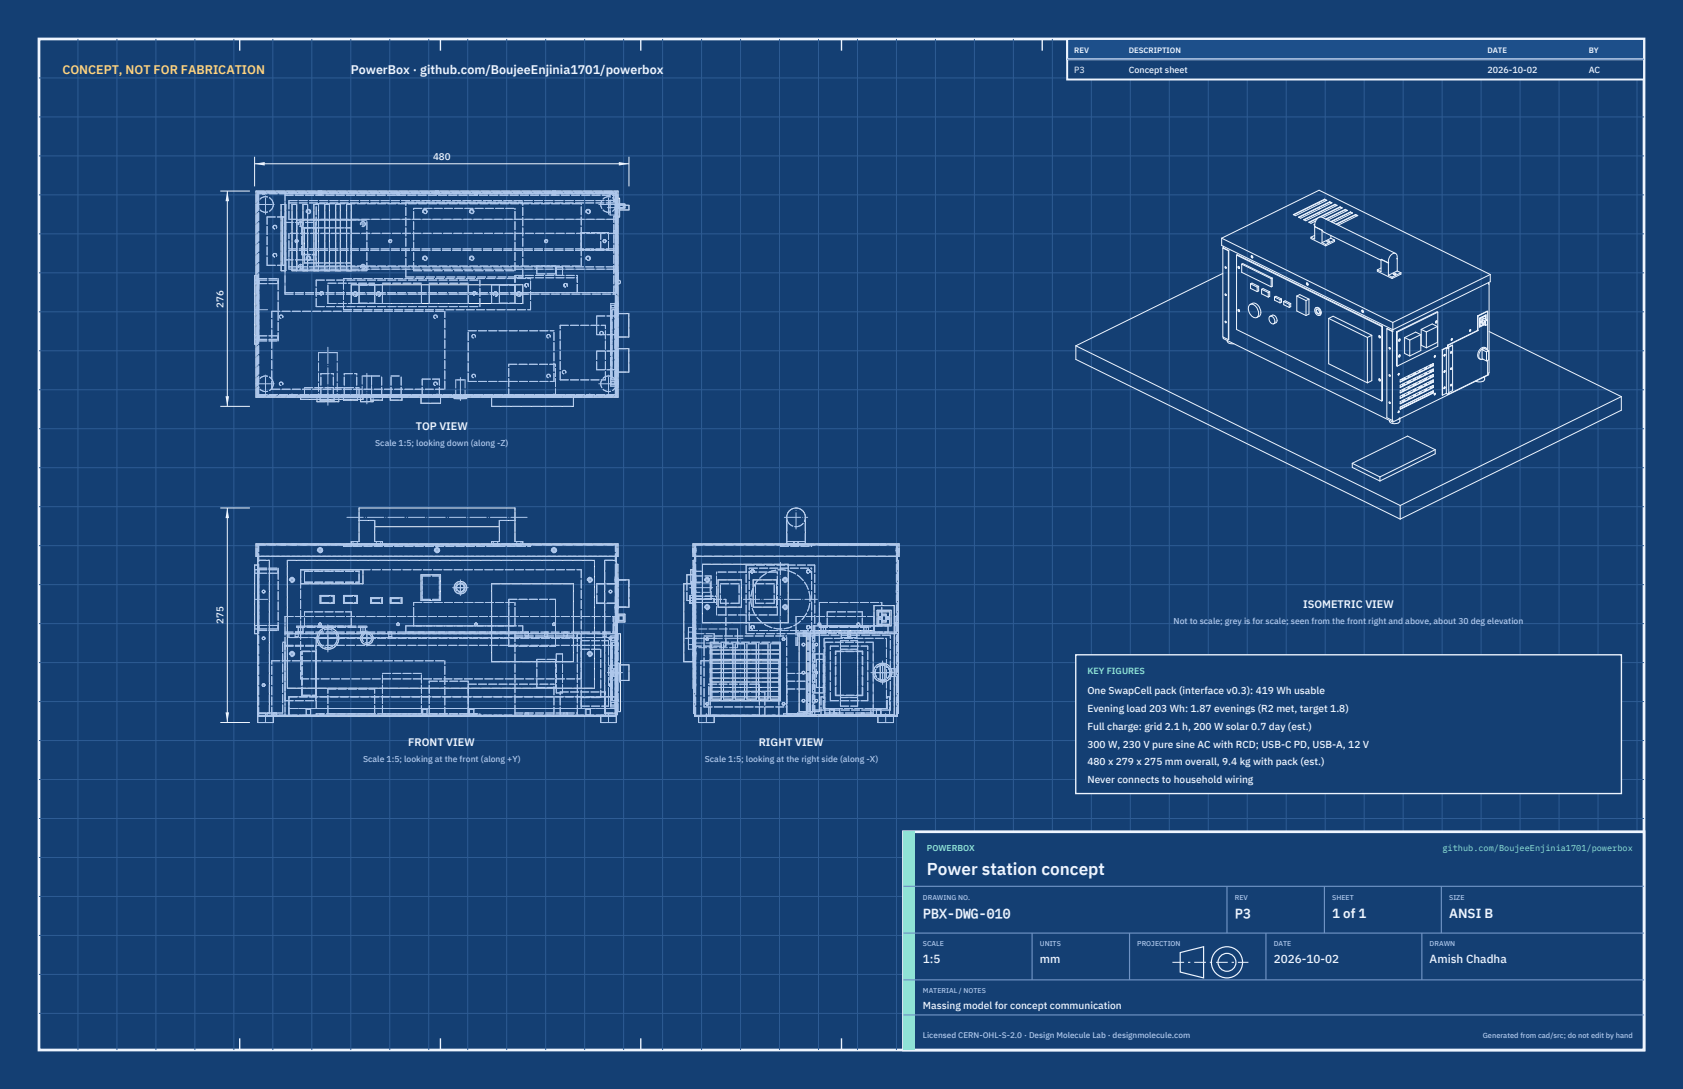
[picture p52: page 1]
CONCEPT, NOT FOR FABRICATION; PowerBox · github.com/BoujeeEnjinia1701/powerbox; FRONT VIEW; TOP VIEW; RIGHT VIEW; ISOMETRIC VIEW; REV; DESCRIPTION; DATE; Concept sheet; POWERBOX; github.com/BoujeeEnjinia1701/powerbox; DRAWING NO. PBX-DWG-010; REV P3; SHEET 1 of 1; SIZE ANSI B; SCALE 1:5; UNITS mm; PROJECTION; DRAWN Amish Chadha; Licensed CERN-OHL-S-2.0 · Design Molecule Lab · designmolecule.com; Generated from cad/src; do not edit by hand

Scale 1:5; looking down (along -Z)

Not to scale; grey is for scale; seen from the front right and above, about 30 deg elevation

KEY FIGURES
One SwapCell pack (interface v0.3): 419 Wh usable
Evening load 203 Wh: 1.87 evenings (R2 met, target 1.8)
Full charge: grid 2.1 h, 200 W solar 0.7 day (est.)
300 W, 230 V pure sine AC with RCD; USB-C PD, USB-A, 12 V
480 x 279 x 275 mm overall, 9.4 kg with pack (est.)
Never connects to household wiring

Scale 1:5; looking at the front (along +Y)

Scale 1:5; looking at the right side (along -X)

Power station concept

MATERIAL / NOTES
Massing model for concept communication

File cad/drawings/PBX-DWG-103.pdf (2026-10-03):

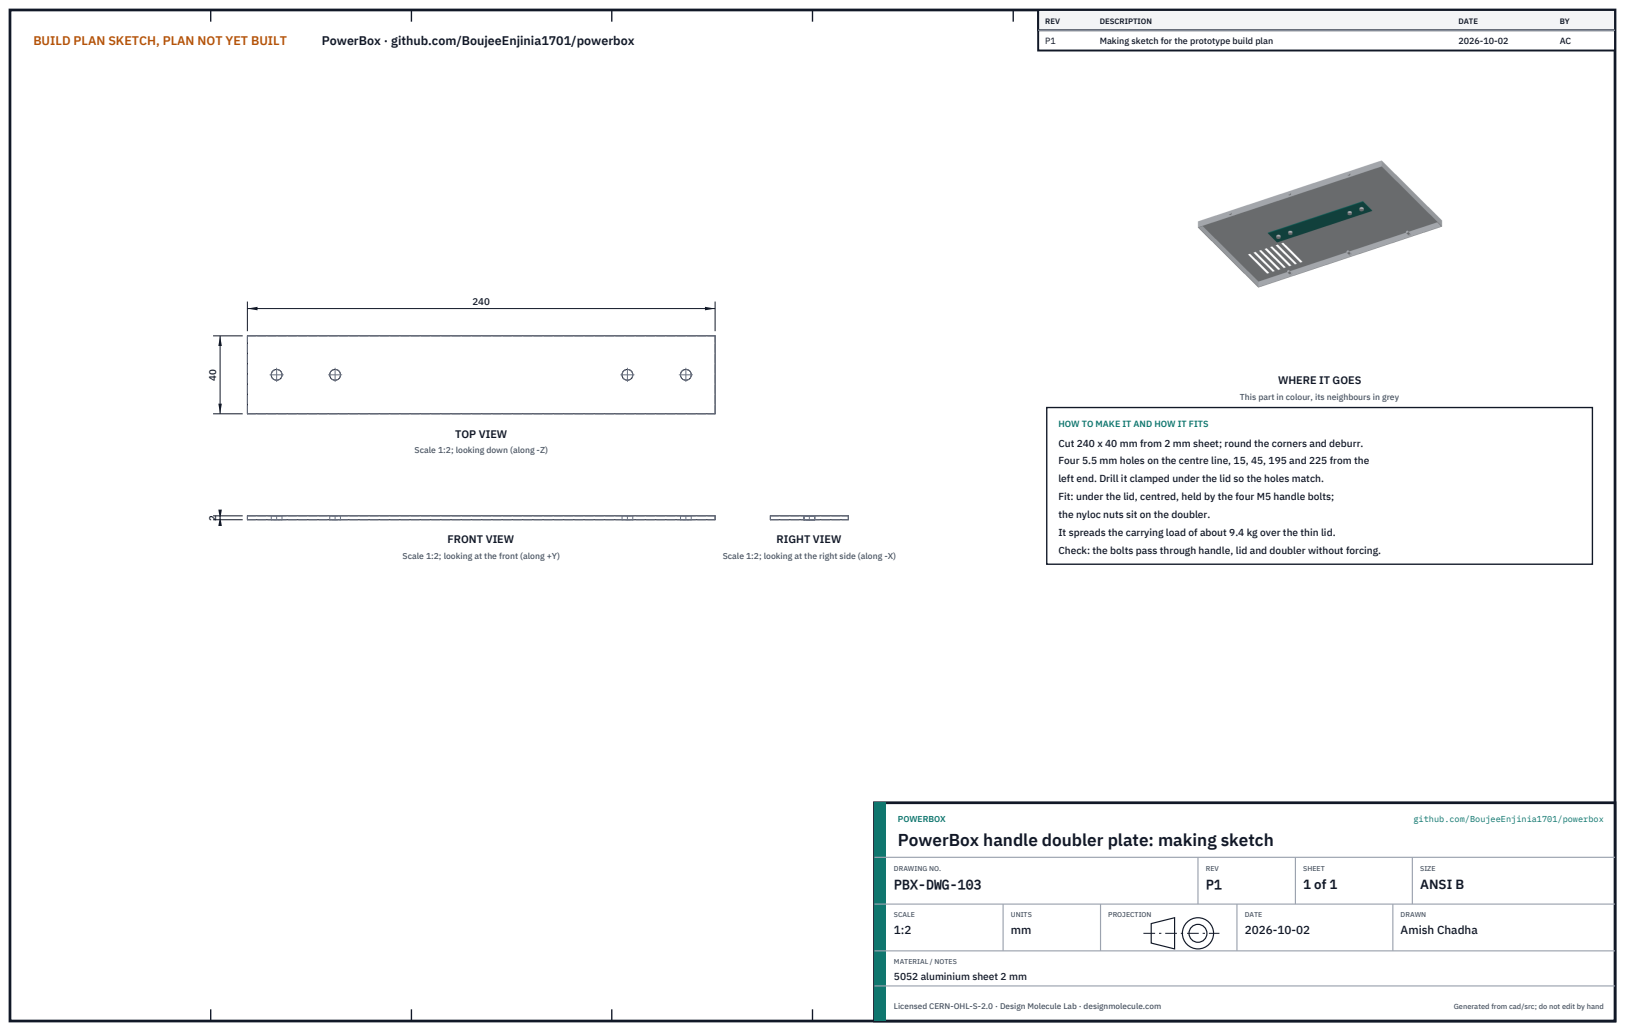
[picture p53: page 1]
BUILD PLAN SKETCH, PLAN NOT YET BUILT; PowerBox · github.com/BoujeeEnjinia1701/powerbox; FRONT VIEW; TOP VIEW; RIGHT VIEW; REV; DESCRIPTION; DATE; Making sketch for the prototype build plan; POWERBOX; github.com/BoujeeEnjinia1701/powerbox; DRAWING NO. PBX-DWG-103; REV P1; SHEET 1 of 1; SIZE ANSI B; SCALE 1:2; UNITS mm; PROJECTION; DRAWN Amish Chadha; Licensed CERN-OHL-S-2.0 · Design Molecule Lab · designmolecule.com; Generated from cad/src; do not edit by hand

WHERE IT GOES

This part in colour, its neighbours in grey

HOW TO MAKE IT AND HOW IT FITS
Cut 240 x 40 mm from 2 mm sheet; round the corners and deburr.
Four 5.5 mm holes on the centre line, 15, 45, 195 and 225 from the
left end. Drill it clamped under the lid so the holes match.
Fit: under the lid, centred, held by the four M5 handle bolts;
the nyloc nuts sit on the doubler.
It spreads the carrying load of about 9.4 kg over the thin lid.
Check: the bolts pass through handle, lid and doubler without forcing.

Scale 1:2; looking down (along -Z)

Scale 1:2; looking at the front (along +Y)

Scale 1:2; looking at the right side (along -X)

PowerBox handle doubler plate: making sketch

MATERIAL / NOTES
5052 aluminium sheet 2 mm

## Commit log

2026-09-24 Initial scaffold: standard open hardware layout, CERN-OHL-S v2 + MIT licenses
    Claude-Session: https://claude.ai/code/session_01XuhhSU4W6fYhgCfURbrkut
    [bom.csv]
2026-09-25 Adopt portfolio kit v1.3.0: session commands, scale figure, 3D viewer, flow diagrams
    Adds .claude/commands (/populate, /advance-trl3, /rein-in, /refresh-media)
    so every Claude Code session starts from the standard prompts, and extends
    concept media with a 1.75 m scale figure, an interactive glTF viewer and
    system or energy flow diagrams. TRL cap 3 unchanged.
    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
2026-09-25 Kit v1.3.1: renderer fixes from the TremorTrace pilot
    Context scale parts for small objects, cutaway exclusions, and text
    labels in flow diagrams.
    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
2026-09-25 Populate powerbox to a strong TRL 2 with concept media (batch 2)
    Problem, requirements and precis v0.2, massing model and concept media,
    indicative BOM, docs/REVIEW.md with decisions proposed and awaiting Amish.
    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
    [bom.csv]
2026-09-25 Remove StepGen as a PowerBox charging source
    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
2026-09-25 Advance powerbox to TRL 3 (batch 2)
    Decisions approved by Amish 2026-09-25 recorded in DDR-001. TRL 4 is on hold.
    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
    [bom.csv, powerbox-assembly.step, powerbox-assembly.stl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]
2026-09-26 Accept all recommendations (DDR-002), switch footer to designmolecule.com, add README write-up with new inspiration point
    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
    [powerbox-assembly.step, powerbox-enclosure.step, powerbox-pack-bay.step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]
2026-09-27 Product appearance model and photoreal renders
    Adds cad/src/product_model.py (appearance model for renders only, all main
    dimensions from model.py) and Blender renders in media/render-*.png,
    captioned with the project, repository and viewing direction. README leads
    with the product render; trl stays 3.
    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
2026-10-01 Image quality pass: legible exploded views, flow diagrams and drawing sheets
    Kit 1.6.1 image layout: the parts list sits in its own column, number bubbles sit on visible parts and never overlap, small parts get a leader, pictures are cropped to the subject, flow labels keep numbers with their units, and sheet captions and the revision table no longer overprint. Concept images, blueprint and general arrangement sheet regenerated; repo-specific labels moved clear of other text and lines.
2026-10-01 Kit 1.7.0: constructable design, illustrated build plan and design decisions register
    The design is now constructable: every part can be made and fits its neighbours, with each change recorded in a Design for construction decision record (made under Amish's 2026-09-30 instruction; ope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
    FlexHand also credits Dr. Geeti Chadha as a contribut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
    [bom.csv, powerbox-assembly.step, powerbox-assembly.stl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]
2026-10-02 Record Amish's approval of the open-decision recommendations
    Amish approved the recommendation on every open decision in the design decisions register ("i approve your recommendations for all 555 open decisions.", 2026-10-02). Each decision is moved to Decisio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
2026-10-03 Carry approved follow-ups into the design and redo photoreal renders
    Amish approved the follow-up actions from the open-decision sign-off ("APPROVED CHANGES, COMPLETE THESE", 2026-10-02), the design-for-construction change tables in ten repos, the last wave's open dec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
    [bom.csv, powerbox-assembly.step, powerbox-assembly.stl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]

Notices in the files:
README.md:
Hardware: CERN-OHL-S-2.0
